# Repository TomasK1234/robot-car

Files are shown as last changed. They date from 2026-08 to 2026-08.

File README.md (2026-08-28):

# WiFi-Controlled Robot Car

A two-wheeled robot car driven entirely from a phone browser over its own local WiFi network — no app, no internet connection required. Built from scratch as a first hardware project, with zero prior electronics experience going in.

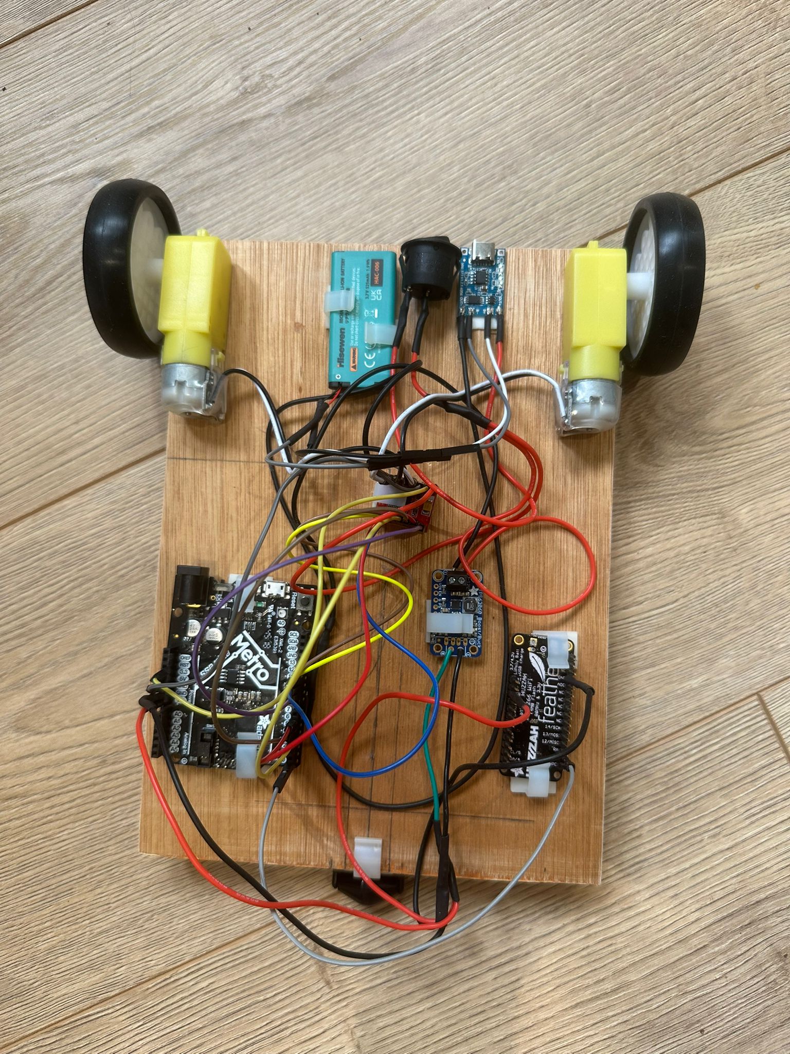
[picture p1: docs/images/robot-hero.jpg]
Robot car


## Features

* Drive forward, backward, left, and right from any phone or laptop browser
* Robot creates its own WiFi access point — connect and go, no router needed
* Press-and-hold controls with automatic stop on connection loss (500ms safety timeout)
* Simple plywood chassis, two-microcontroller architecture: one board dedicated to WiFi/web serving, one dedicated to real-time motor control

## How it works

```
Phone browser  →  WiFi  →  Feather HUZZAH (web server)
                              │
                              │ UART (single-byte command protocol)
                              ▼
                           Metro M0 Express
                              │
                              │ PWM + direction signals
                              ▼
                         TB6612FNG motor driver
                              │
                              ▼
                          2× TT DC motors
```

The HUZZAH hosts a small web page with directional buttons and handles all WiFi/HTTP traffic. It continuously streams a single command byte to the Metro M0 over a dedicated hardware UART. The Metro M0 is solely responsible for real-time motor timing — this split exists because the ESP8266's WiFi stack introduces unpredictable timing interrupts that make it unreliable for driving PWM directly.

See [`docs/build-log.md`](docs/build-log.md) for the full reasoning behind this architecture, including two failed alternatives.

## Hardware

Full parts list and approximate cost: [`hardware/bill-of-materials.md`](hardware/bill-of-materials.md)

Wiring diagram: [`hardware/wiring-diagram.svg`](hardware/wiring-diagram.svg)

Core components:

* Adafruit Metro M0 Express — motor control logic
* Adafruit Feather HUZZAH (ESP8266) — WiFi + web server
* DollaTek TB6612FNG dual motor driver
* 2× TT DC gear motors
* Adafruit Verter (buck-boost) — regulated logic power
* 3.7V Li-Ion cell + TP4056 USB-C charging board
* 9mm plywood base plate chassis

## Firmware

* [`firmware/metro/`](firmware/metro) — motor control, command decoding, timeout safety
* [`firmware/feather/`](firmware/feather) — WiFi access point, web server, control interface

Both are Arduino sketches. See inline comments for pin mappings — these must match your own wiring if you're replicating this build.

## Chassis

The final chassis is a simple 9mm plywood base plate — components are mounted directly to it, no walls or enclosure. This was a late change from the original plan: an earlier two-tier chassis was fully designed in Fusion 360 first, including parametric sizing driven by every component's measured footprint, but it was never built as designed. That exploration is kept in [`cad/fusion-360-exploration/`](cad/fusion-360-exploration) as a record of the design process — **it does not reflect the final physical build**. See the build log for why.

## Build log

This project went through two full power-architecture rewrites and a fair amount of trial and error — the AA battery pack that couldn't supply peak motor current, a single-cell + boost converter approach that didn't provide enough voltage headroom, and the eventual move to a 3.7V Li-Ion cell with a smaller motor driver. The full story, including the reasoning at each step, is documented in [`docs/build-log.md`](docs/build-log.md).

## License

MIT — see [`LICENSE`](LICENSE). Free to use, modify, and build on.

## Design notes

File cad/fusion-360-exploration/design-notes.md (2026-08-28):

# Fusion 360 Design Exploration — NOT the final chassis

This folder contains the original two-tier chassis design worked through in
Fusion 360, including parametric width/length calculations driven by
component footprints (motor driver, battery, breadboard, Arduino, etc.).

**This design was not used for the final build.** The robot was ultimately
built from a single sheet of 9mm plywood, cut to size, with no walls or
two-tier structure. The dimensions and parameters in this file (3mm wall
thickness, 84x167mm footprint, 20mm tier height) do not correspond to
anything in the physical robot.

It's kept here as a record of the design process -- working through
component layout, tolerance reasoning, and parametric CAD fundamentals --
rather than as a build reference. See the main build log
(../../docs/build-log.md) for why the design diverged from the plan.

If you're replicating this build, use the plywood dimensions noted in
the build log instead, not this file.

Add chassis-concept.f3d here if you want to keep the actual Fusion
source file alongside these notes.

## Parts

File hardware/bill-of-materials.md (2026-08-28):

# Bill of Materials

|Component|Qty|Notes|Approx. cost (GBP)|
|-|-|-|-|
|Adafruit Metro M0 Express|1|Motor control logic|\~£20|
|Adafruit Feather HUZZAH (ESP8266)|1|WiFi + web server|\~£15|
|DollaTek TB6612FNG dual motor driver|1|2.5–13.5V motor supply, 2.7–5.5V logic|\~£3–5|
|TT DC gear motor|2|\~71×20×22mm, 6V rated, runs fine at 3–4V|\~£3|
|Adafruit Verter|1|Buck-boost, regulates logic supply to 5.2V|\~£8|
|3.7V Li-Ion cell (Hisewen HAC-006, 525mAh)|1|Repurposed Nintendo Switch Joy-Con battery|\~£5–8|
|TP4056 USB-C charging board|1|With OUT+/OUT- protected output|\~£1–2|
|Dupont jumper wires (M-M, M-F)|assorted||\~£3–5 for a mixed kit|
|9mm plywood sheet|1|Chassis base plate, cut to size|\~£3–8 depending on offcut size|
|TT motor wheels, 65mm|2|If not already owned|\~£3–5|
|Multimeter|1|Essential for verifying voltages before powering on|\~£11–13|
|Slide switch|1|Main power cutoff, wired on positive rail|\~£1|

**Not used in final build (originally sourced, later replaced):**

* DFRobot DC Motor Driver 2×15A Lite - oversized for this project's current/voltage needs, see build log
* 4×AA NiMH battery holder + cells - replaced by single Li-Ion cell, see build log
* Adafruit Perma-Proto half-size breadboard - originally used for connections, later soldered wires together and removed the breadboard

## Tools required

* Soldering iron + solder
* Wire strippers
* Small screwdriver set
* Computer with Arduino IDE (ESP8266 and SAMD/Adafruit board packages installed)
* Fusion 360 (student/personal license) for chassis CAD

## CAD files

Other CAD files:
cad/fusion-360-exploration/car-chassis-v1.f3d

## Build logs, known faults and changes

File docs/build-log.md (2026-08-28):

# Build Log

This is the unfiltered version of how this project actually came together — including the parts that didn't work the first time. Kept here rather than in the README because it's long, but it's arguably the most useful part of this repo if you're trying to learn from it rather than just clone it.

\---

## Power architecture — attempt 1: 4×AA NiMH pack

**Setup:** 4× rechargeable NiMH AA cells (6V nominal) feeding a DFRobot 2×15A motor driver directly, Adafruit Verter regulating 5.2V for logic.

**Symptom:** Motors worked on the bench with no load, but stalled or clicked without turning once any real resistance was applied (e.g. driving on carpet).

**Diagnosis:** TT motor stall current is \~1.1A each — 2.2A combined peak. NiMH cells have relatively high internal resistance, so pack voltage sagged well below the motor driver's 4.8V minimum the instant real current was demanded.

**Also discovered along the way:** the motor driver's screw terminals need to be fully tightened — a loose connection caused one motor to intermittently drop out, which looked like a wiring fault but was just a loose screw.

\---

## Power architecture — attempt 2: single-cell Li-Ion + 5V boost

**Reasoning:** NiMH sag was the root cause, so switch to LiPo/Li-Ion chemistry which handles current spikes much better, and keep the motor driver's minimum voltage requirement in mind.

**Setup:** 3.7V Li-Ion cell boosted to 5V via a boost converter, feeding the same DFRobot motor driver.

**Symptom:** Motors didn't spin at all — not even weakly.

**Diagnosis:** Tested with a lab-style power bank capable of supplying a controlled 5V at 2–3A — still no motor movement. This confirmed the problem was voltage, not available current. 5V was simply too close to the motor driver's stated 4.8V minimum once any real-world drop was accounted for, and evidently the DFRobot driver needed more headroom in practice than the datasheet minimum suggested.

**Root cause:** Chose a motor driver sized for much larger motors/current (2×15A) than this project needed, which meant its practical operating envelope didn't suit a low-voltage, low-current setup.

\---

## Power architecture — attempt 3 (final): 3.7V direct + smaller motor driver

**Change:** Switched to a DollaTek TB6612FNG driver, rated for 2.5–13.5V motor supply and 2.7–5.5V logic supply — both ranges comfortably cover a bare 3.7V Li-Ion cell.

**Result:** Motors ran directly off the 3.7V cell with no boost conversion needed on the motor side. Verter retained purely for logic-side regulation (Metro M0, HUZZAH, motor driver VCC).

**Trade-off accepted:** TB6612FNG is rated 1.2A continuous per channel against a 1.1A motor stall current — a thin margin. Acceptable for normal driving; sustained stall (e.g. wedged against furniture) should be avoided.

\---

## Battery selection and charging

Went through several options before landing on a repurposed 3.7V 525mAh Nintendo Switch Joy-Con battery (Hisewen HAC-006):

* **7.4V 2S LiPo** — rejected. No affordable module exists that combines USB-C charging *and* proper per-cell balance charging. Non-balancing USB-C boards are common but risk long-term cell drift on a 2-cell pack.
* **Better-quality NiMH (Eneloop Pro)** — a genuinely valid alternative that was ultimately not pursued once the smaller motor driver made single-cell Li-Ion viable, but worth considering as a simpler, safer option if avoiding LiPo entirely.
* **Single-cell Li-Ion (final choice)** — no balance charging needed since there's only one cell. TP4056 USB-C charging board handles it directly.

**Known compromise:** the TP4056 board's default charge current (1000mA) is roughly 2C for a 525mAh cell — higher than the ideal 0.5–1C. The battery's built-in protection circuit provides a safety backstop (it will cut charging if it gets too hot), but the correct fix is replacing the board's SMD programming resistor to bring charge current down to \~500mA. Not yet done on this build — flagged here for anyone replicating this.

\---

## Communication protocol

Settled on a single-byte command protocol between the HUZZAH and Metro M0 (`0xFF` = forward, `0x01` = backward, `0xAA` = right, `0x55` = left, `0x00` = stop) sent continuously over hardware UART, rather than one message per button press. This was a deliberate choice: continuous transmission acts as an implicit heartbeat, so a 500ms timeout on the Metro M0 can detect a dropped WiFi connection and stop the motors automatically, rather than the robot driving indefinitely on the last command received.

Rejected alternatives: I2C and SoftwareSerial were both considered to avoid the HUZZAH's hardware TX pin conflicting with USB traffic during development. Both were dropped — I2C because the ESP8266's WiFi interrupts make it an unreliable I2C master, and SoftwareSerial for the same underlying interrupt-timing reason. The simpler fix was powering the HUZZAH from a standalone supply (not USB) during real operation, and accepting the USB conflict only during development/flashing.

\---

## Chassis — Fusion 360 design vs. plywood reality

Fully worked through a two-tier chassis design in Fusion 360: measured every
component (motors, motor driver, battery, breadboard, Arduino, ESP8266),
derived the internal width/length from the widest and longest components on
each tier, added wall thickness and clearance as parameters, and used a
mirror operation to build the four walls symmetrically. Chassis footprint
ended up at 84×167mm with 3mm walls and a 20mm internal tier height.

That design was never actually printed. The final build is a single sheet
of **9mm plywood**, cut to size as a flat base plate with no walls, no
two-tier structure, and none of the CAD dimensions carried over. The
Fusion file is kept in `cad/fusion-360-exploration/` purely as a record of
the design reasoning — component-driven layout, tolerance thinking, and
learning parametric CAD from scratch — not as a build reference for anyone
replicating this project.

If replicating: the plywood base needs to be large enough to fit the
motor driver, battery, breadboard, Metro M0, and HUZZAH with reasonable
spacing between them — refer to the component dimensions in
`hardware/bill-of-materials.md` rather than the Fusion file's dimensions.

\---

## Hardware mishaps

* **USB-A vs USB-C cable:** the TP4056 board didn't respond to a USB-C to USB-C cable from a modern PD power bank — needed a USB-A to USB-C cable instead. Cheap USB-C charging boards frequently lack PD negotiation support.
* **Cold solder joints:** early motor driver soldering attempts failed because solder was applied to the iron rather than to the (pre-heated) joint. Tinning both the wire and the pad separately before joining fixed this.
* **Hot glue on PCBs:** would likely have damaged components if used hot glue to attach them to the base, so used self adhesive cable clips instead.

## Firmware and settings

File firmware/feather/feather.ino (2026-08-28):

#include <ESP8266WiFi.h>
#include <ESP8266WebServer.h>

// ============================================================
// CONFIGURATION — edit these
// ============================================================
const char* WIFI_SSID     = "Robot Car";      // network name your phone connects to
const char* WIFI_PASSWORD = "Vroom123";      // password for that network

// Command bytes — must match Metro M0 definitions exactly
#define CMD_FORWARD  0xFF
#define CMD_BACKWARD 0x01
#define CMD_RIGHT    0xAA
#define CMD_LEFT     0x55
#define CMD_STOP     0x00

// ============================================================
// WEB SERVER
// ============================================================
ESP8266WebServer server(80);    // 80 is the standard HTTP port

// ============================================================
// CURRENT STATE
// ============================================================
byte currentCommand = CMD_STOP;

const char INDEX_HTML[] PROGMEM = R"rawliteral(
<!DOCTYPE html>
<html>
<head>
    <meta charset="UTF-8">
    <meta name="viewport" content="width=device-width, initial-scale=1.0">
    <title>Robot Car</title>

    <style>
        body {
            background: #1a1a1a;
            display: flex;
            justify-content: center;
            align-items: center;
            height: 100vh;
            margin: 0;
            font-family: monospace;
            color: white;
        }
        .controls {
            text-align: center;
        }
        .btn {
            width: 80px;
            height: 80px;
            font-size: 24px;
            margin: 6px;
            cursor: pointer;
            background: #333;
            color: white;
            border: 2px solid #666;
            border-radius: 12px;
            user-select: none;
            -webkit-user-select: none;
        }
        .btn:active {
            background: #555;
        }
        .row {
            display: flex;
            justify-content: center;
        }
        h1, h2, h3 {
            font-family: monospace, sans-serif;
            font-weight: 700;
            font-size: 100px;
            color: pink;
        }
    </style>
</head>
<body>
    <div class="controls">
        <div class="row">
            <h1>Robot Car</h1>
        </div>
        <div class="row">
            <button class="btn" id="forward">▲</button>
        </div>
        <div class="row">
            <button class="btn" id="left">◄</button>
            <button class="btn" id="backward">▼</button>
            <button class="btn" id="right">►</button>
        </div>
    </div>

    <script>
        // ── Command routing ──
        const commands = {
            forward:  '/forward',
            backward: '/backward',
            left:     '/left',
            right:    '/right'
        };

        let activeKey = null;
        let sendInterval = null;

        function startCommand(direction) {
            if (activeKey === direction) return;  // already active
            stopCommand();                         // cancel any previous
            activeKey = direction;
            sendRequest(direction);                // send immediately
            sendInterval = setInterval(() => sendRequest(direction), 100);  // then every 100ms
        }

        function stopCommand() {
            if (sendInterval) {
                clearInterval(sendInterval);
                sendInterval = null;
            }
            activeKey = null;
            sendRequest('stop');
        }

        function sendRequest(direction) {
            fetch(direction === 'stop' ? '/stop' : commands[direction])
                .catch(() => {});   // silently ignore network errors
        }

        // ── Button events (mouse + touch) ──
        document.querySelectorAll('.btn').forEach(btn => {
            btn.addEventListener('mousedown',  () => startCommand(btn.id));
            btn.addEventListener('touchstart', (e) => { e.preventDefault(); startCommand(btn.id); });
            btn.addEventListener('mouseup',    stopCommand);
            btn.addEventListener('touchend',   stopCommand);
            btn.addEventListener('mouseleave', stopCommand);  // finger slides off button
        });

        // ── Keyboard events ──
        const keyMap = {
            'ArrowUp'   : 'forward',
            'ArrowDown' : 'backward',
            'ArrowLeft' : 'left',
            'ArrowRight': 'right'
        };

        document.addEventListener('keydown', (e) => {
            if (keyMap[e.key] && activeKey !== keyMap[e.key]) {
                e.preventDefault();
                startCommand(keyMap[e.key]);
            }
        });

        document.addEventListener('keyup', (e) => {
            if (keyMap[e.key]) stopCommand();
        });
    </script>
</body>
</html>
)rawliteral";

// ============================================================
// ROUTE HANDLERS
// ============================================================
void handleRoot() {
    server.send(200, "text/html", INDEX_HTML);
}

void handleForward() {
    currentCommand = CMD_FORWARD;
    server.send(200, "text/plain", "ok");
}

void handleBackward() {
    currentCommand = CMD_BACKWARD;
    server.send(200, "text/plain", "ok");
}

void handleRight() {
    currentCommand = CMD_RIGHT;
    server.send(200, "text/plain", "ok");
}

void handleLeft() {
    currentCommand = CMD_LEFT;
    server.send(200, "text/plain", "ok");
}

void handleStop() {
    currentCommand = CMD_STOP;
    server.send(200, "text/plain", "ok");
}

// ============================================================
// SETUP
// ============================================================
void setup() {
    Serial.begin(9600);

    // Create WiFi access point
    WiFi.softAP(WIFI_SSID, WIFI_PASSWORD);
    Serial.print("Access point started. IP: ");
    Serial.println(WiFi.softAPIP());   // usually 192.168.4.1

    // Register routes
    server.on("/",        handleRoot);
    server.on("/forward", handleForward);
    server.on("/backward",handleBackward);
    server.on("/right",   handleRight);
    server.on("/left",    handleLeft);
    server.on("/stop",    handleStop);

    server.begin();
    Serial.println("Web server started.");
}

// ============================================================
// LOOP
// ============================================================
void loop() {
    server.handleClient();          // process any incoming HTTP requests
    Serial.write(currentCommand);   // continuously send current state to Metro M0
    delay(50); // Breathing room for the Feather, so as to not overheat unnecessarily.
}

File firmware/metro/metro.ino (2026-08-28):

int AIN1  = 5;
int AIN2  = 6;
int PWMA = 9;
int BIN1 = 10;
int BIN2 = 11;
int PWMB = 12;
int STBY = 4;

#define CMD_FORWARD  0xFF
#define CMD_BACKWARD 0x01
#define CMD_RIGHT    0xAA
#define CMD_LEFT     0x55
#define CMD_STOP     0x00

const unsigned long TIMEOUT_MS = 500;
unsigned long lastCommandTime = 0;

void setup() {
    pinMode(AIN1, OUTPUT);
    pinMode(AIN2, OUTPUT);
    pinMode(PWMA, OUTPUT);

    pinMode(BIN1, OUTPUT);
    pinMode(BIN2, OUTPUT);
    pinMode(PWMB, OUTPUT);

    pinMode(STBY, OUTPUT);
    digitalWrite(STBY, HIGH); // enable motors

    stopMotors();
    
    Serial.begin(9600);
    Serial1.begin(9600);
    
    lastCommandTime = millis();
    
    Serial.println("Metro M0 ready.");
}

void loop() {
    if (Serial1.available() > 0) {
        byte command = Serial1.read();
        lastCommandTime = millis();
        
        switch (command) {
            case CMD_FORWARD:
                digitalWrite(AIN1, LOW);
                digitalWrite(AIN2, HIGH);
                analogWrite(PWMA, 255);

                digitalWrite(BIN1, HIGH);
                digitalWrite(BIN2, LOW);
                analogWrite(PWMB, 255);
                Serial.println("Forward");
                break;
                
            case CMD_BACKWARD:
                digitalWrite(AIN1, HIGH);
                digitalWrite(AIN2, LOW);
                analogWrite(PWMA, 255);

                digitalWrite(BIN1, LOW);
                digitalWrite(BIN2, HIGH);
                analogWrite(PWMB, 255);
                Serial.println("Backward");
                break;
                
            case CMD_RIGHT:
                digitalWrite(AIN1, HIGH);
                digitalWrite(AIN2, LOW);
                analogWrite(PWMA, 255);

                digitalWrite(BIN1, HIGH);
                digitalWrite(BIN2, LOW);
                analogWrite(PWMB, 255);

                Serial.println("Right");
                break;
                
            case CMD_LEFT:
                digitalWrite(AIN1, LOW);
                digitalWrite(AIN2, HIGH);
                analogWrite(PWMA, 255);

                digitalWrite(BIN1, LOW);
                digitalWrite(BIN2, HIGH);
                analogWrite(PWMB, 255);
                Serial.println("Left");
                break;
                
            case CMD_STOP:
            default:
                stopMotors();
                Serial.println("Stop");
                break;
        }
    }
    
    if (millis() - lastCommandTime > TIMEOUT_MS) {
        stopMotors();
    }
}

void stopMotors() {
    digitalWrite(AIN1, LOW);
    digitalWrite(AIN2, LOW);
    analogWrite(PWMA, 0);

    digitalWrite(BIN1, LOW);
    digitalWrite(BIN2, LOW);
    analogWrite(PWMB, 0);
}   

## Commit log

2026-08-28 Initial commit: working WiFi robot car
    [car-chassis-v1.f3d]
2026-08-28 Updated bill of materials file
2026-08-28 Add wiring diagram matching final architecture
